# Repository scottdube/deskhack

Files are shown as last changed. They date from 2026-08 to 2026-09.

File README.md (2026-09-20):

# deskhack

Home Assistant control and height readback for an **ErgoSwiss hydraulic standing
desk** running a **LOGICDATA COMPACT-e-3-VAL-ES-US** control box ("Compact-3-eco",
software V290) — without buying the vendor Memory handset, and without opening
either sealed box.

The desk shipped with a dumb up/down panel: no presets, no display. This project
taps the 7-pin DIN handset cable inline, drives the button lines from an ESP32
through optocouplers, and reads the desk's height from a previously undocumented
serial broadcast the control box sends on one of the handset pins. The original
panel keeps working in parallel.

As far as I can tell this is the first public decode of the COMPACT-e-**3**
handset bus. The well-known reverse-engineering projects
([RoboDesk](https://github.com/phord/RoboDesk),
[logicdata-standing-desk](https://github.com/DanielHabenicht/logicdata-standing-desk))
target the COMPACT-e-2L, whose framing differs in an important way (see below).

## The protocol

Everything below was measured on real hardware with a $12 FX2LP logic analyzer
and `sigrok-cli`; nothing is copied from other models' documentation.

### Physical

7-pin DIN (DIN 45329 family) between handset and control box. Wire colours in
the cheap extension cable used for the tap:

| wire | function |
|---|---|
| brown  | GND |
| red | +5V supply to handset |
| white  | HS line — assert **high** to drive **UP** |
| yellow | HS line — assert **high** to drive **DOWN** |
| green  | HS line, unused by the basic panel (memory functions) |
| blue | HS line, unused by the basic panel (memory functions) |
| black  | serial data **out of** the box, idles high |

Button lines are **active-high** and high-impedance: the box's inputs are
sensitive enough that a multimeter in ohms mode will command motion (ask me how
I know). A dumb panel is nothing but switches connecting HS lines to the +5V
rail.

### Serial framing

The data line is **1000 baud, 9 data bits, no parity, 1 stop, LSB-first** — a
classic 9-bit multi-drop bus. Community docs for the COMPACT-e-2L describe
"1000 baud with even parity"; on this box that is a misread of the 9th data
bit. The framing here was solved by constraint propagation over the raw bit
runs (every 0 must sit inside a frame; see `dataline.py` and `messages.py`),
not assumed.

Packets are two 9-bit words, sent only **when the displayed height changes**
(one packet per inch of travel) plus a fixed handshake burst at the start of
any button press. Packet: `0x07F` header, then the payload word.

### Height

```
height_inches = (245 - (payload & 0xFF)) / 2
```

Verified against a tape measure at four points across the full travel
(69–96 cm on this desk, 27.0–38.0 in): every reading within 0.5 cm. The box
counts pump-motor Hall pulses internally, so this is the same position the
controller itself acts on.

### The 8N1 trick

You do not need 9-bit UART support to read this bus — a plain **8N1** UART at
1000 baud recovers every payload byte intact. But how the packet arrives
depends on how the UART handles framing errors, and real ESP32 silicon
differs from the obvious simulation:

- A UART that **discards** error bytes and resyncs bit-by-bit (what a naive
  software decoder does) sees the header mis-frame into a constant `0xFE`
  sync marker followed by the height byte.
- The **ESP32 keeps** framing-error bytes (verified on an ESP32-WROOM-32,
  ESP-IDF 5.5). Packets arrive as `00 7F <payload>`: the header comes through
  verbatim as `0x7F`, each framing error also emits a `0x00` artifact, and
  the payload byte is unmangled.

Either way the sync-then-payload structure survives. On the ESP32: skip
`0x00`, treat `0x7F` as "next byte is payload".

Filtering the handshake burst is easy thanks to an accident of the encoding:
**real heights are always odd bytes** (`245 - 2*inches`), and the handshake
constants are even or outside the travel range — except `0x0BF`, which
aliases a true 27.0 in reading. Its tell is timing: as a handshake word it
arrives within ~400 ms of the others, as a real height it arrives alone, so
reject `0xBF` seen within 600 ms of other handshake traffic. The working
lambda is in `desk.yaml`.

## Hardware

Eight components, all through-hole:

- 2 × PC817 optocoupler (or CPC1017N photoMOS) — GPIO drives the LED through
  330 Ω; the output side connects a button line to the +5V rail, exactly as a
  finger on the panel does
- 2 × 100 kΩ bleed, opto emitter → GND, so leakage can't float the
  high-impedance inputs
- 3 × 22 kΩ — divider (22k : 44k) dropping the 5 V data line to 3.3 V for the
  ESP32's RX
- ESP32 dev board on its own USB supply, grounds tied at the DIN cable

The tap itself is a male-female 7-pin DIN extension cable cut in half and
landed on lever nuts, so the whole thing unplugs back to stock in seconds.

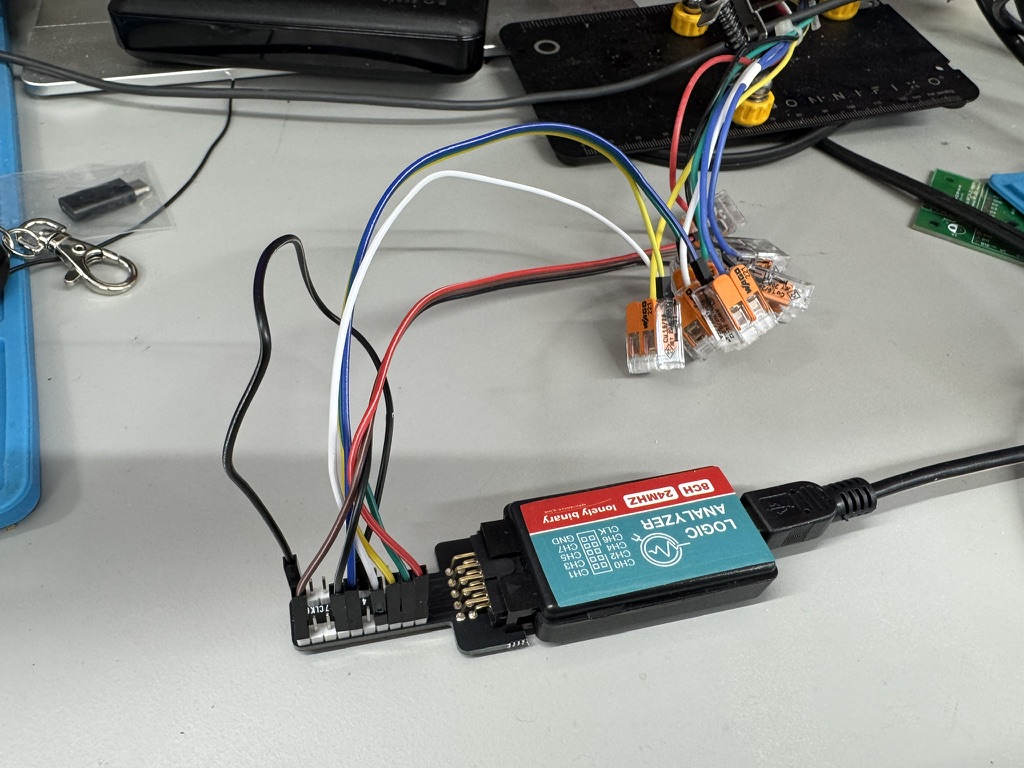
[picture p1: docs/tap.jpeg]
The tap: a 7-pin DIN extension cut in half, each conductor landed in a WAGO 221 lever nut with a pigtail out to the logic analyzer


Nothing is soldered and nothing on the desk is modified — the box and the
original panel each keep their own connector, and the lever nuts sit in
between. Pull the two halves and the desk is stock again.

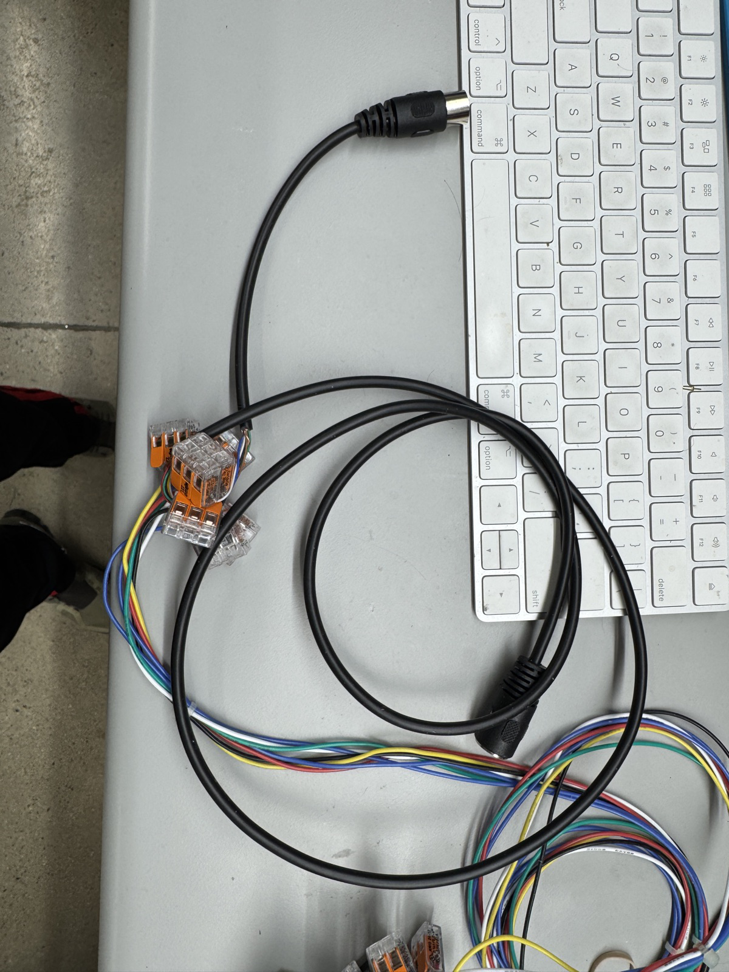
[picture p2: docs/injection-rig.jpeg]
The injection rig: a cheap male-female 7-pin DIN extension cut in half, both halves landed in WAGO 221 lever nuts. Male end to the control box, female end to the original handset.


**This rig is the whole trick, and it generalises.** It is a $10 extension
cable, not the desk's harness. Cutting it gives you seven conductors broken out
into lever nuts, which is simultaneously a **probe point** for the logic
analyzer and an **injection point** for the ESP32 — read the bus and drive it
without ever putting a knife near the cable that came with the machine. Get it
wrong, unplug two connectors, and the desk has never been touched. Any bus
that runs through a detachable cable can be attacked this way.

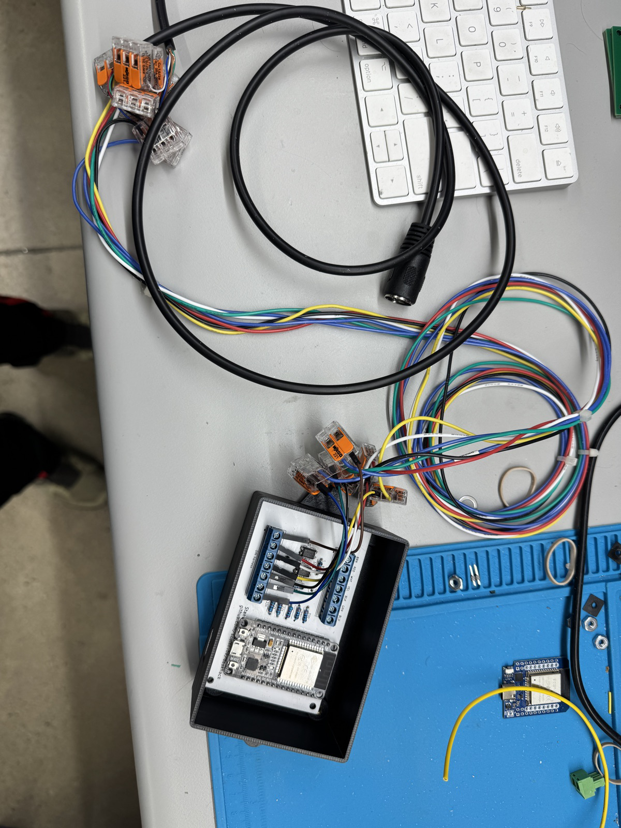
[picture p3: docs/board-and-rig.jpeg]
The finished board wired to the rig on the bench, before install. The wire-colour legend along each terminal block matches the DIN conductor colours.


The board keeps the same idea: J1 and J4 are wired straight through, so the
control box and the original handset each land on their own terminal block and
the ESP32 sits across the pair. The panel goes on working exactly as before.

### The cable shield is left floating — on purpose

The handset cable is seven conductors **plus a shield**, and the shield is not
grounded here. That is deliberate, and it is worth stating plainly because the
instinct on seeing an ungrounded shield is that somebody forgot.

**It is not grounded in the desk's own wiring.** The two halves of the tap have
their drains joined to each other, so the shield stays electrically continuous
end to end exactly as it was before the cable was cut — and it terminates
nowhere, exactly as it did before.

Why not "improve" it: **the whole design goal is that the control box cannot
tell the difference.** Everything else here is built that way — the original
panel keeps working, the box keeps its own connector, nothing is soldered to
the desk. Bonding the shield to logic ground would be a change to a mains-fed
system whose internal grounding we cannot see, in exchange for a benefit
nothing has demonstrated a need for. If the box grounds the shield at its end,
adding a second bond creates a loop.

No idea *why* LOGICDATA left it floating. Matching what the manufacturer did is
the conservative choice when you do not know the reason.

`kicad/` contains a KiCad 10 project (ERC-clean, footprints assigned) with the
interface circuit and a 30-pin ESP32 DevKit V1 socket, ready for board layout.
The schematic is *generated* — edit `kicad/gen_sch.py` and rerun rather than
editing the sheet, or retire the generator once you start hand-routing.

## Firmware

`desk.yaml` is a complete ESPHome configuration:

- height sensor via the 8N1 trick (hardware UART, zero protocol code)
- target-height number entity + sit/stand/stop buttons for Home Assistant
- bang-bang seek loop (feedback is 1-inch granular; there is nothing finer to
  chase)
- **duty-cycle watchdog** — the box is rated 2 min on / 18 min off and this is
  enforced in firmware, don't remove it; Drive Budget and Budget Recovery
  sensors expose how much motion is left before lockout. The budget persists
  across reboots (and credits real elapsed time while powered off), so an OTA
  can't hand you a fresh one. A diagnostic **Reset Duty Budget** button exists
  for bench work — deliberate operator action only, never automate it
- stall detection (no height change while driving → stop)
- a template **cover** face (0% = bottom of travel, 100% = top) so voice
  assistants can drive it with built-in position intents — no custom
  sentences required, and it provides a voice "stop"

### Voice control: use the cover, not the buttons

The cover face is not a convenience — on Home Assistant it is the *only* part of
this firmware a voice assistant can reach without extra configuration, and that
is worth stating plainly because the sit/stand buttons look like the obvious
target.

HA's local sentence matcher only recognises entities in a fixed set of domains.
Measured against `home-assistant-intents` (en, 851 sentence templates): every
template with a `{name}` slot carries a `requires_context.domain` allow-list, and
the union of every domain any template can target is

    binary_sensor climate cover fan input_boolean lawn_mower light lock
    media_player person scene script sensor switch todo vacuum valve weather

**`button` is not in that set.** So `button.<device>_sit` / `_stand` cannot be
matched by any phrasing — and **entity aliases do not help**, because an alias
only supplies candidate text for a `{name}` slot and there is no `{name}`
template that accepts a button.

What this costs depends on your pipeline. With a purely local assistant, the
buttons are simply unreachable by voice. With an LLM conversation agent and
"prefer handling commands locally" enabled, they still work — but they miss the
local matcher every time and fall through to the LLM, so every "sit"/"stand"
pays a full cloud round trip while `cover` commands answer instantly. That
asymmetry is easy to misread as a problem with the desk, the ESP32 or the WiFi;
it is none of those.

Two ways to get fast sit/stand:

- **Use the cover.** "raise / lower the standing desk" works with no extra
  config. Note the cover's ends are the ends of *travel*, so "lower" goes to the
  bottom of travel, which may be below your preferred sitting height.
- **Add custom sentences** mapping your own phrases to an `intent_script` that
  presses the buttons. This keeps one definition of "sit" and "stand" — in this
  firmware, next to the duty-cycle watchdog — and preserves a non-travel-end
  sitting height.

Copy `wifi.yaml.example` to `wifi.yaml` first.

## Analysis tools

Everything runs on a capture exported to CSV
(`sigrok-cli -i cap.sr -O csv > cap.csv`):

| tool | what it does |
|---|---|
| `probe.py` | per-channel characterization: idle level, edges, implied baud from narrowest pulse |
| `timeline.py` | button lines as a deglitched state timeline |
| `dataline.py` | bit-time histogram and exhaustive UART framing search |
| `messages.py` | packet segmentation + solved 9N1 decode — the useful one |
| `viewer.py` | renders a capture as a self-contained interactive HTML waveform viewer |
| `make_test_capture.py` | synthetic capture for self-testing the toolchain |

## Safety notes

- The control box is mains-fed and sealed. Nothing here requires opening it,
  and you shouldn't.
- Disconnect mains before plugging/unplugging anything on the handset cable —
  the box enters a re-commissioning state (down-only until re-homed) if the
  handset connection glitches while powered.
- Respect the 2/18 duty cycle. A "nudge every N minutes" automation will
  overheat the box; preset seeks lasting seconds are fine.
- If the box loses its reference: drive to the bottom, hold both panel buttons
  5 s, drive to the top, hold both 5 s (the §4.2 commissioning procedure — it
  works with a plain up/down panel).

## Applies to

Verified on: ErgoSwiss "Steuerung Compact-3-eco 110V V290" (P/N 124.30290),
LOGICDATA type `COMPACT-e-3-VAL-ES-US`, revision 3/1.9.14, US 120 V. The VAL
firmware is hydraulic-specific ("only for hydraulic lift system — modified
parameters"). Other COMPACT-e-3 variants likely match; measure before you
trust — `probe.py` will tell you in one capture.

## License

MIT. If this saved you a €63 handset or an afternoon with a logic analyzer,
pay it forward.

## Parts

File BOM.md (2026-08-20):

# Bill of materials — Standing Desk Controller

ESPHome controller for the LOGICDATA standing desk (deskhack) - PC817 opto interface, ESP32

**InvenTree part** `#795`  ·  **Build** `BO-0003` (Complete)

| Qty | Part | ID | Where it lives |
|---:|---|---|---|
| 1 | ESP-WROOM-32 ESP32 ESP-32S Dev Board 2.4GHz WiFi+BT | `62` | B3-R6C3 |
| 1 | 7-Pin DIN Male-Female Extension Cable 5ft | `786` | no stock |
| 3 | Resistor 22k 1% 1/4W | `621` | Kit - EAONE Resistor 30-value |
| 2 | Resistor 100k 1% 1/4W | `625` | Kit - EAONE Resistor 30-value |
| 2 | Resistor 330R 1% 1/4W | `611` | Kit - EAONE Resistor 30-value |
| 2 | (8Sets) Terminal Block Set, 3 4 5 6 7 8 10 12 Positions 600V 15A Dual Row Screw Terminals Strip + Pr | `283` | no stock |
| 2 | PC817 Optocoupler DIP-4 | `17` | B3-R3C1 |

## Notes on individual lines

- **7-Pin DIN Male-Female Extension Cable 5ft** — Desk-to-controller handset cable

---

_Generated from InvenTree on 2026-08-19 — do not edit by hand._
_Regenerate:_ `itq run link_repos.py && write_boms.py`

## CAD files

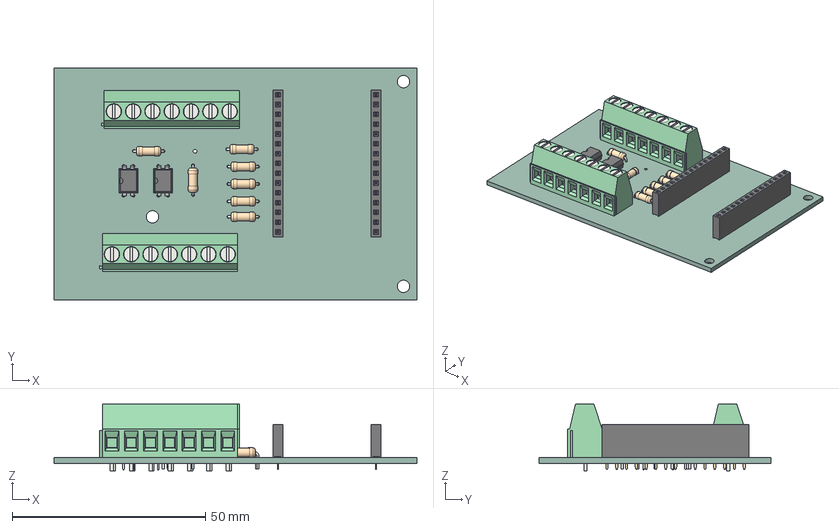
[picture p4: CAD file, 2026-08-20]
mech/desk-board.step
94.0 x 60.0 x 17.3 mm
PinSocket_1x15_P2.54mm_Vertical x 2
DIP-4_W7.62mm x 2
R_Axial_DIN0207_L63mm_D25mm_P762mm_Horizontal x 7
TerminalBlock_Phoenix_MKDS-1,5-7_1x07_P5.00mm_Horizontal x 2
desk_PCB

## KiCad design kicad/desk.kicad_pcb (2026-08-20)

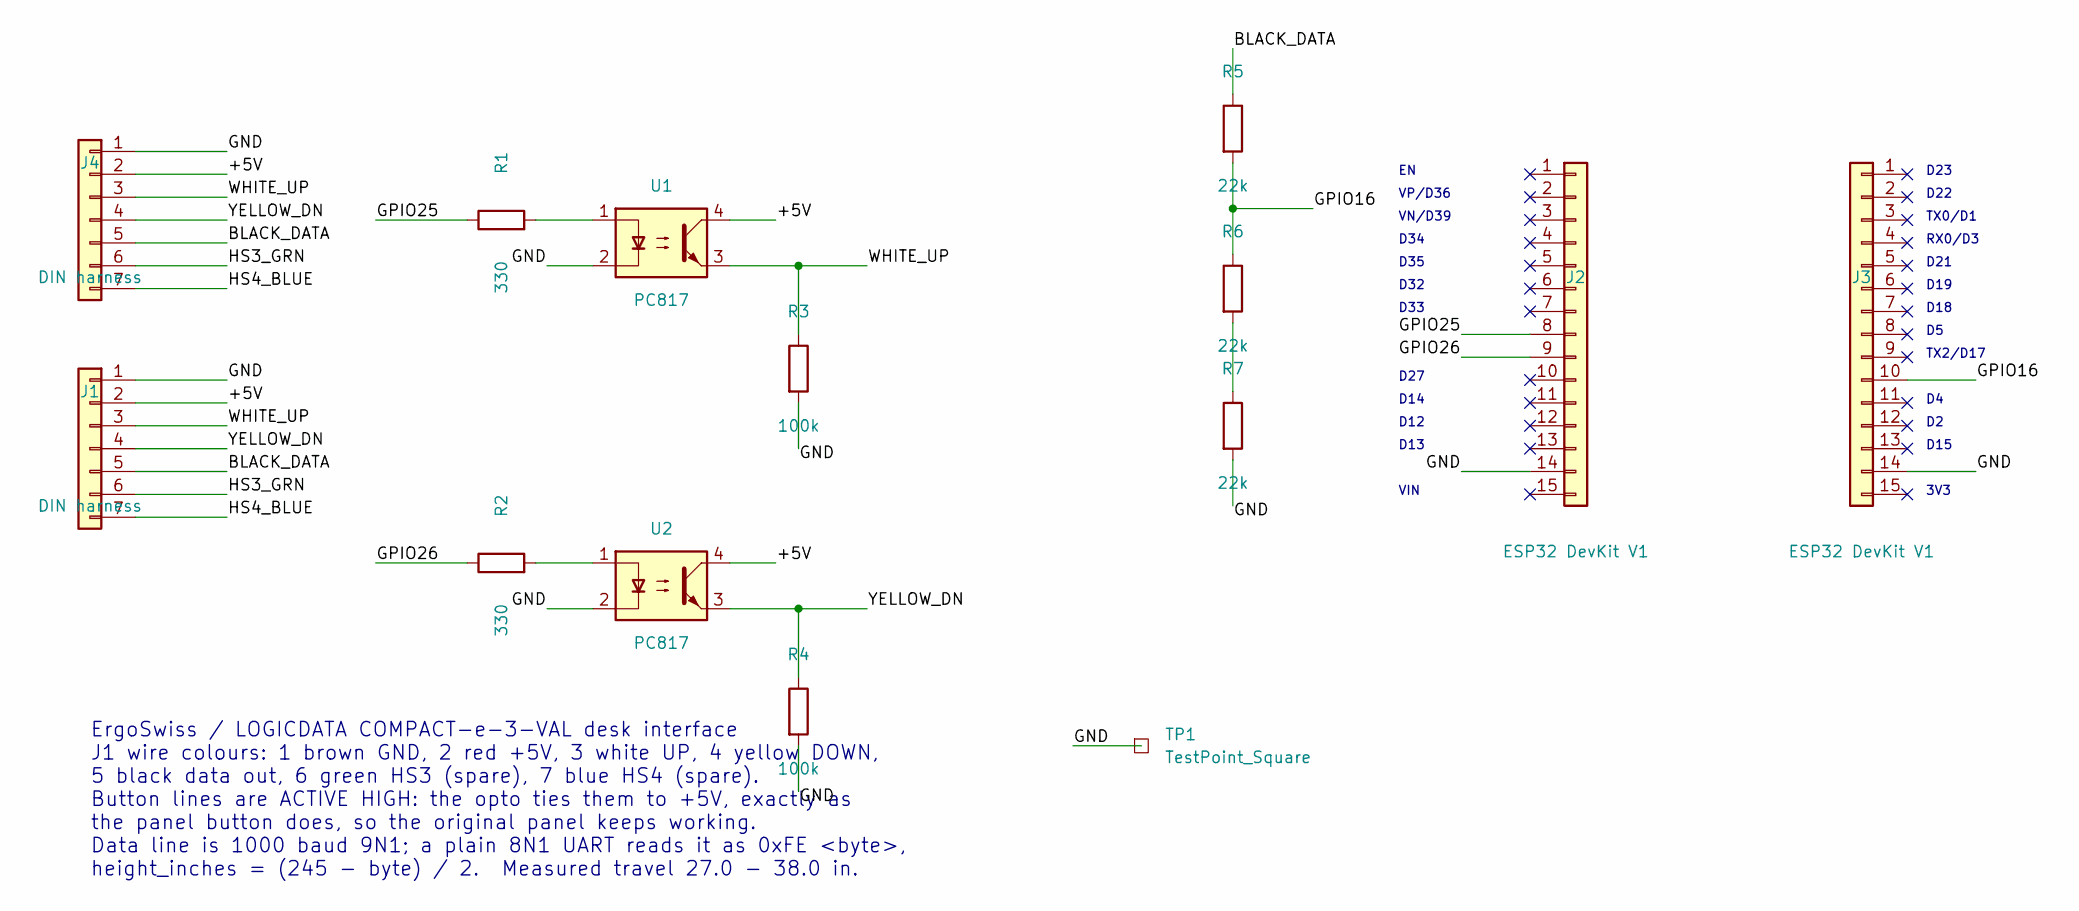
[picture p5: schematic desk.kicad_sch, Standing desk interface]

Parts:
J1, J4: DIN harness; TerminalBlock_Phoenix_MKDS-1,5-7_1x07_P5.00mm_Horizontal
J2, J3: ESP32 DevKit V1; PinSocket_1x15_P2.54mm_Vertical
R1, R2: 330; R_Axial_DIN0207_L6.3mm_D2.5mm_P7.62mm_Horizontal
R3, R4: 100k; R_Axial_DIN0207_L6.3mm_D2.5mm_P7.62mm_Horizontal
R5, R6, R7: 22k; R_Axial_DIN0207_L6.3mm_D2.5mm_P7.62mm_Horizontal
TP1: TestPoint_Square; TestPoint_Pad_2.0x2.0mm
U1, U2: PC817; DIP-4_W7.62mm

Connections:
/+5V: J1.2, J4.2, U1.4, U2.4
/BLACK_DATA: J1.5, J4.5, R5.1
/GND: J1.1, J2.14, J3.14, J4.1, R3.2, R4.2, R7.2, TP1.1 (1_1), U1.2, U2.2
/GPIO16: J3.10, R5.2, R6.1
/GPIO25: J2.8, R1.1
/GPIO26: J2.9, R2.1
/HS3_GRN: J1.6, J4.6
/HS4_BLUE: J1.7, J4.7
/WHITE_UP: J1.3, J4.3, R3.1, U1.3
/YELLOW_DN: J1.4, J4.4, R4.1, U2.3
unnamed: R1.2, U1.1
unnamed: R2.2, U2.1
unnamed: R6.2, R7.1

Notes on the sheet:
D12
D35
ErgoSwiss / LOGICDATA COMPACT-e-3-VAL desk interface J1 wire colours: 1 brown GND, 2 red +5V, 3 white UP, 4 yellow DOWN, 5 black data out, 6 green HS3 (spare), 7 blue HS4 (spare). Button lines are ACTIVE HIGH: the opto ties them to +5V, exactly as the panel button does, so the original panel keeps 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
RX0/D3
D33
D19
D18
TX2/D17
D22
3V3
D23
TX0/D1
D32
D14
D15
D21
D34
D13
VP/D36
VN/D39
VIN
D27

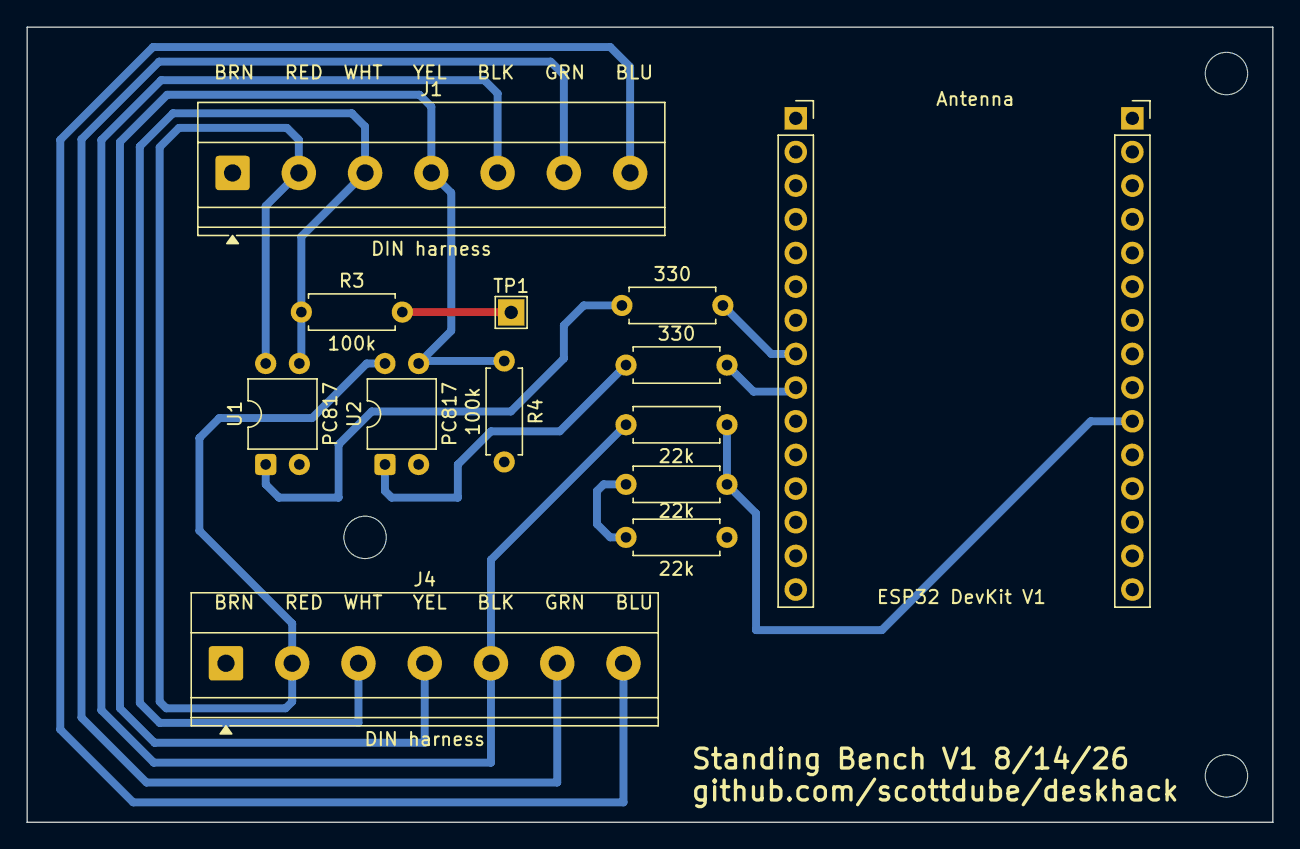
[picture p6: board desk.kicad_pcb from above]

Board: 2 copper layers, 94.0 x 60.0 mm, 14 parts (0 on the bottom side), 13 nets.

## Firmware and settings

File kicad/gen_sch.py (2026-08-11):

#!/usr/bin/env python3
"""Generate the desk interface schematic as a KiCad 10 project.

Usage:
    python3 gen_sch.py [outdir]

Symbol definitions are lifted from the installed KiCad libraries and embedded
in the .kicad_sch, so the file opens standalone without library lookups.
"""
import os
import sys
import uuid as uuidlib

import sexp

LIB = "/Applications/KiCad/KiCad.app/Contents/SharedSupport/symbols"
NS = uuidlib.UUID("6f2b1d3e-0000-4000-8000-000000000000")
SHEET = "b1c0ffee-0000-4000-8000-000000000001"

_n = [0]


def uid():
    """Deterministic UUIDs so regenerating gives a clean diff."""
    _n[0] += 1
    return str(uuidlib.uuid5(NS, str(_n[0])))


# ---------------------------------------------------------------- symbols

_cache = {}


def libsym(lib, name):
    if (lib, name) not in _cache:
        tree = sexp.parse(open(f"{LIB}/{lib}.kicad_sym").read())
        for s in sexp.find(tree, "symbol"):
            if s[1] == f'"{name}"':
                _cache[(lib, name)] = s
                break
        else:
            raise KeyError(f"{lib}:{name}")
    return _cache[(lib, name)]


def pins_of(lib, name):
    """{number: (x, y)} in symbol space, from every unit/body-style block."""
    out = {}
    for sub in sexp.find(libsym(lib, name), "symbol"):
        for p in sexp.find(sub, "pin"):
            at = sexp.first(p, "at")
            num = sexp.first(p, "number")[1].strip('"')
            out[num] = (float(at[1]), float(at[2]))
    return out


def place_pin(px, py, x, y, rot, mirror):
    """Symbol-space pin -> sheet coordinates.

    Schematic Y runs downward while symbol Y runs up, hence the negation.
    """
    if mirror == "y":
        px = -px
    if rot == 0:
        dx, dy = px, -py
    elif rot == 90:
        dx, dy = py, px
    elif rot == 180:
        dx, dy = -px, py
    elif rot == 270:
        dx, dy = -py, -px
    else:
        raise ValueError(rot)
    return (round(x + dx, 4), round(y + dy, 4))


# ---------------------------------------------------------------- emitters

items = []
used = {}


def comp(lib, name, ref, value, x, y, rot=0, mirror=None, footprint="",
         val_off=6.35):
    used[(lib, name)] = True
    pins = pins_of(lib, name)
    body = [f'\t(symbol\n\t\t(lib_id "{lib}:{name}")\n\t\t(at {x} {y} {rot})']
    if mirror:
        body.append(f"\t\t(mirror {mirror})")
    body.append(
        f"\t\t(unit 1)\n\t\t(exclude_from_sim no)\n\t\t(in_bom yes)\n"
        f"\t\t(on_board yes)\n\t\t(dnp no)\n\t\t(uuid \"{uid()}\")"
    )
    for pname, pval, off, hide in (
        ("Reference", ref, -6.35, False),
        ("Value", value, val_off, False),
        ("Footprint", footprint, 0, True),
        ("Datasheet", "~", 0, True),
    ):
        h = "\n\t\t\t\t(hide yes)" if hide else ""
        body.append(
            f'\t\t(property "{pname}" "{pval}"\n'
            f"\t\t\t(at {x} {round(y + off, 4)} 0)\n"
            f"\t\t\t(effects\n\t\t\t\t(font\n\t\t\t\t\t(size 1.27 1.27)\n"
            f"\t\t\t\t){h}\n\t\t\t)\n\t\t)"
        )
    for num in sorted(pins, key=lambda s: (len(s), s)):
        body.append(f'\t\t(pin "{num}"\n\t\t\t(uuid "{uid()}")\n\t\t)')
    body.append(
        f'\t\t(instances\n\t\t\t(project "desk"\n\t\t\t\t(path "/{SHEET}"\n'
        f'\t\t\t\t\t(reference "{ref}")\n\t\t\t\t\t(unit 1)\n'
        f"\t\t\t\t)\n\t\t\t)\n\t\t)"
    )
    body.append("\t)")
    items.append("\n".join(body))
    return {n: place_pin(*p, x, y, rot, mirror) for n, p in pins.items()}


def wire(a, b):
    items.append(
        f"\t(wire\n\t\t(pts\n\t\t\t(xy {a[0]} {a[1]}) (xy {b[0]} {b[1]})\n"
        f"\t\t)\n\t\t(stroke\n\t\t\t(width 0)\n\t\t\t(type default)\n\t\t)\n"
        f'\t\t(uuid "{uid()}")\n\t)'
    )


def label(text, at, rot=0, justify="left bottom"):
    items.append(
        f'\t(label "{text}"\n\t\t(at {at[0]} {at[1]} {rot})\n\t\t(effects\n'
        f"\t\t\t(font\n\t\t\t\t(size 1.27 1.27)\n\t\t\t)\n"
        f"\t\t\t(justify {justify})\n\t\t)\n"
        f'\t\t(uuid "{uid()}")\n\t)'
    )


def junction(at):
    items.append(
        f"\t(junction\n\t\t(at {at[0]} {at[1]})\n\t\t(diameter 0)\n"
        f"\t\t(color 0 0 0 0)\n"
        f'\t\t(uuid "{uid()}")\n\t)'
    )


def noconn(at):
    items.append(f'\t(no_connect\n\t\t(at {at[0]} {at[1]})\n\t\t(uuid "{uid()}")\n\t)')


def note(text, at, size=1.27):
    esc = text.replace("\n", "\\n")
    items.append(
        f'\t(text "{esc}"\n\t\t(exclude_from_sim no)\n'
        f"\t\t(at {at[0]} {at[1]} 0)\n\t\t(effects\n\t\t\t(font\n"
        f"\t\t\t\t(size {size} {size})\n\t\t\t)\n\t\t\t(justify left top)\n"
        f'\t\t)\n\t\t(uuid "{uid()}")\n\t)'
    )


# ---------------------------------------------------------------- circuit

def build():
    # ---- DIN harness in, on the left, mirrored so its pins face the circuit
    j1 = comp("Connector_Generic", "Conn_01x07", "J1", "DIN harness",
              63.5, 101.6, mirror="y",
              footprint="TerminalBlock_Phoenix:TerminalBlock_Phoenix_MKDS-1,5-7_1x07_P5.00mm_Horizontal")
    names = {
        "1": ("GND", "brown"),
        "2": ("+5V", "red"),
        "3": ("WHITE_UP", "white"),
        "4": ("YELLOW_DN", "yellow"),
        "5": ("BLACK_DATA", "black"),
    }
    for num, (net, colour) in names.items():
        p = j1[num]
        end = (p[0] + 10.16, p[1])
        wire(p, end)
        label(net, end)
    for num in ("6", "7"):                      # green / blue, HS3 / HS4
        p = j1[num]
        end = (p[0] + 5.08, p[1])
        wire(p, end)
        noconn(end)

    # ---- opto channels. PC817: 1 anode, 2 cathode, 3 emitter, 4 collector.
    for ref_u, ref_r, ref_b, gpio, net, y in (
        ("U1", "R1", "R3", "GPIO25", "WHITE_UP", 76.2),
        ("U2", "R2", "R4", "GPIO26", "YELLOW_DN", 114.3),
    ):
        r = comp("Device", "R", ref_r, "330", 109.22, y, rot=90,
                 footprint="Resistor_THT:R_Axial_DIN0207_L6.3mm_D2.5mm_P10.16mm_Horizontal")
        u = comp("Isolator", "PC817", ref_u, "PC817", 127.0, y + 2.54,
                 footprint="Package_DIP:DIP-4_W7.62mm")
        label(gpio, (r["2"][0] - 10.16, y))
        wire((r["2"][0] - 10.16, y), r["2"])
        wire(r["1"], u["1"])                      # series R into the LED

        wire(u["2"], (u["2"][0] - 5.08, u["2"][1]))   # cathode to ground
        label("GND", (u["2"][0] - 5.08, u["2"][1]), justify="right bottom")

        wire(u["4"], (u["4"][0] + 5.08, u["4"][1]))   # collector to +5V
        label("+5V", (u["4"][0] + 5.08, u["4"][1]))

        # Emitter drives the desk's button line, with a bleed to ground so
        # phototransistor leakage cannot float a high-impedance input high.
        tap = (u["3"][0] + 15.24, u["3"][1])
        wire(u["3"], tap)
        label(net, tap)
        bleed = comp("Device", "R", ref_b, "100k", u["3"][0] + 7.62,
                     u["3"][1] + 11.43,
                     footprint="Resistor_THT:R_Axial_DIN0207_L6.3mm_D2.5mm_P10.16mm_Horizontal")
        junction((bleed["1"][0], u["3"][1]))
        wire((bleed["1"][0], u["3"][1]), bleed["1"])
        wire(bleed["2"], (bleed["2"][0], bleed["2"][1] + 5.08))
        label("GND", (bleed["2"][0], bleed["2"][1] + 5.08), justify="left top")

    # ---- 3:1 divider dropping the 5V data line to 3.33V for the ESP32
    x = 190.5
    label("BLACK_DATA", (x, 57.15), justify="left bottom")
    r5 = comp("Device", "R", "R5", "22k", x, 66.04,
              footprint="Resistor_THT:R_Axial_DIN0207_L6.3mm_D2.5mm_P10.16mm_Horizontal")
    r6 = comp("Device", "R", "R6", "22k", x, 83.82,
              footprint="Resistor_THT:R_Axial_DIN0207_L6.3mm_D2.5mm_P10.16mm_Horizontal")
    r7 = comp("Device", "R", "R7", "22k", x, 99.06,
              footprint="Resistor_THT:R_Axial_DIN0207_L6.3mm_D2.5mm_P10.16mm_Horizontal")
    wire((x, 57.15), r5["1"])
    tap = (x, 74.93)
    wire(r5["2"], r6["1"])
    junction(tap)
    wire(tap, (x + 15.24, 74.93))
    label("GPIO16", (x + 15.24, 74.93))
    wire(r6["2"], r7["1"])
    wire(r7["2"], (x, 107.95))
    label("GND", (x, 107.95), justify="left top")

    # ---- ESP32 DevKit V1 (30-pin) as the two socket rows a carrier board
    # actually holds. Silk names run EN..VIN down the left row and
    # D23..3V3 down the right row with the USB jack at the bottom.
    LEFT = ["EN", "VP/D36", "VN/D39", "D34", "D35", "D32", "D33",
            "D25", "D26", "D27", "D14", "D12", "D13", "GND", "VIN"]
    RIGHT = ["D23", "D22", "TX0/D1", "RX0/D3", "D21", "D19", "D18", "D5",
             "TX2/D17", "RX2/D16", "D4", "D2", "D15", "GND", "3V3"]
    NETS = {"D25": "GPIO25", "D26": "GPIO26", "RX2/D16": "GPIO16",
            "GND": "GND"}
    for ref, x, names, mirror in (("J2", 228.6, LEFT, None),
                                  ("J3", 260.35, RIGHT, "y")):
        j = comp("Connector_Generic", "Conn_01x15", ref,
                 "ESP32 DevKit V1", x, 88.9, mirror=mirror, val_off=24.13,
                 footprint="Connector_PinSocket_2.54mm:"
                           "PinSocket_1x15_P2.54mm_Vertical")
        sign = 1 if mirror else -1          # stub direction away from body
        for i, silk in enumerate(names, 1):
            p = j[str(i)]
            if silk in NETS:
                end = (round(p[0] + sign * 7.62, 4), p[1])
                wire(p, end)
                label(NETS[silk], end,
                      justify="left bottom" if sign > 0 else "right bottom")
            else:
                # Unused socket position: flag it, annotate the silk name as
                # plain text so it does not become a one-pin net.
                noconn(p)
                tx = round(p[0] + sign * 2.0, 4)
                note(silk, (tx if sign > 0 else tx - 12.7, p[1] - 0.8),
                     size=1.0)

    note("ErgoSwiss / LOGICDATA COMPACT-e-3-VAL desk interface\\n"
         "J1 wire colours: 1 brown GND, 2 red +5V, 3 white UP, 4 yellow DOWN,\\n"
         "5 black data out, 6 green HS3 (spare), 7 blue HS4 (spare).\\n"
         "Button lines are ACTIVE HIGH: the opto ties them to +5V, exactly as\\n"
         "the panel button does, so the original panel keeps working.\\n"
         "Data line is 1000 baud 9N1; a plain 8N1 UART reads it as 0xFE <byte>,\\n"
         "height_inches = (245 - byte) / 2.  Measured travel 27.0 - 38.0 in.",
         (63.5, 132.08), size=1.6)


# ---------------------------------------------------------------- output

def write(outdir):
    build()
    libs = []
    for (lib, name) in used:
        blk = sexp.dump(libsym(lib, name), indent=2)
        libs.append(blk.replace(f'(symbol "{name}"', f'(symbol "{lib}:{name}"', 1))

    doc = [
        "(kicad_sch",
        "\t(version 20260306)",
        '\t(generator "eeschema")',
        '\t(generator_version "10.0")',
        f'\t(uuid "{SHEET}")',
        '\t(paper "A4")',
        "\t(title_block",
        '\t\t(title "Standing desk interface")',
        '\t\t(company "deskhack")',
        '\t\t(comment 1 "ESP32 <-> ErgoSwiss compact-3-eco handset bus")',
        "\t)",
        "\t(lib_symbols",
        "\n".join(libs),
        "\t)",
        "\n".join(items),
        "\t(sheet_instances",
        '\t\t(path "/"',
        '\t\t\t(page "1")',
        "\t\t)",
        "\t)",
        "\t(embedded_fonts no)",
        ")",
    ]
    os.makedirs(outdir, exist_ok=True)
    with open(f"{outdir}/desk.kicad_sch", "w") as f:
        f.write("\n".join(doc) + "\n")
    with open(f"{outdir}/desk.kicad_pro", "w") as f:
        f.write('{\n  "board": {},\n  "boards": [],\n  "libraries": '
                '{"pinned_footprint_libs": [], "pinned_symbol_libs": []},\n'
                '  "meta": {"filename": "desk.kicad_pro", "version": 3},\n'
                '  "net_settings": {"classes": [{"name": "Default", '
                '"clearance": 0.2, "track_width": 0.25}]},\n'
                '  "sheets": [["' + SHEET + '", "Root"]],\n'
                '  "text_variables": {}\n}\n')
    print(f"wrote {outdir}/desk.kicad_sch")


if __name__ == "__main__":
    write(sys.argv[1] if len(sys.argv) > 1 else ".")

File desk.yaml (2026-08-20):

substitutions:
  device_name: desk
  friendly_name: Standing Desk

# ErgoSwiss hydraulic standing desk on a LOGICDATA COMPACT-e-3-VAL-ES-US
# control box ("Compact-3-eco", software V290). Full reverse-engineering
# writeup: https://github.com/scottdube/deskhack
#
# ============================ ARCHITECTURE (settled 2026-08-11) ==============
# Tap on the 7-pin DIN handset cable, inline between box and the original
# up/down panel (panel keeps working in parallel). Wire colours are the cut
# extension cable's, verified by measurement — NOT the DIN pin numbers.
#
#   brown  GND     red +5V     white UP     yellow DOWN     black data-out
#   green/blue = HS3/HS4, unused by the dumb panel (memory-handset lines)
#
# BUTTON LINES ARE ACTIVE-HIGH and high-impedance: a press connects the line
# to +5V (an ohmmeter's source current was enough to command motion). Drive:
#   GPIO -> 330R -> PC817 LED; opto output ties line to +5V like a finger.
#   100k bleed emitter->GND so leakage can't float an input high.
#   Optos release dark => unpowered/booting ESP32 cannot move the desk.
#
# HEIGHT: the box broadcasts on black at 1000 baud 9N1 (9-bit multi-drop),
# one packet per INCH of displayed change plus a handshake burst on any
# button press. A plain 8N1 UART recovers the payload; on real ESP32
# silicon (which KEEPS framing-error bytes) each packet arrives as
# 00 7F <payload>: skip 0x00, sync on 0x7F, then inches = (245 - b) / 2.
# Real heights are always ODD bytes; handshake words are even, gated, or
# (0xBF only) rejected by a 600ms timing guard. Details in the RX lambda.
# Verified against tape at 4 points across full travel, all within 0.5 cm.
# Overnight drift test 2026-08-12: none (77 cm -> 77 cm under load).
#
# CHANNELS (30-pin DevKit V1):
#   D25 GPIO25 -> opto U1 -> white  (UP)
#   D26 GPIO26 -> opto U2 -> yellow (DOWN)
#   RX2 GPIO16 <- 22k / (22k+22k) divider <- black (5V bus, 3.3V pin)
#
# DUTY CYCLE: the box is rated 2 min on / 18 min off and the watchdog below
# enforces it. Do not remove it, do not build nudge-every-N-minutes
# automations on top of this device.

esphome:
  name: ${device_name}
  friendly_name: ${friendly_name}
  on_boot:
    priority: -100
    then:
      - script.execute: all_stop

esp32:
  board: esp32dev
  framework:
    type: esp-idf

logger:

api:

ota:
  - platform: esphome

# Copy wifi.yaml.example -> wifi.yaml and fill it in. wifi.yaml is gitignored.
wifi: !include wifi.yaml

time:
  - platform: homeassistant
    id: ha_time
    on_time_sync:
      then:
        # First valid clock after boot: credit the cooldown that elapsed while
        # we were off. Guarded by a one-shot so periodic re-syncs don't
        # double-decay against the 500ms loop that also drains run_s.
        - if:
            condition:
              lambda: return !id(budget_credited);
            then:
              - lambda: |-
                  id(budget_credited) = true;
                  auto now = id(ha_time).now();
                  if (!now.is_valid() || id(budget_stamp) == 0) return;
                  uint32_t t = now.timestamp;
                  if (t <= id(budget_stamp)) return;
                  float off_s = (float) (t - id(budget_stamp));
                  id(run_s) = fmaxf(0.0f, id(run_s) - 0.1f * off_s);
                  if (id(run_s) <= 0.0f) id(locked_out) = false;
                  ESP_LOGI("desk", "credited %.0fs offline, budget now %.0f%%",
                           off_s, 100.0f - id(run_s));

uart:
  id: deskbus
  rx_pin: GPIO16
  baud_rate: 1000
  data_bits: 8
  parity: NONE
  stop_bits: 1
  # Commissioning aid: dump raw RX bytes to the log. Height packets appear
  # as 00 7F <byte> groups. Remove once the bus is proven.
  debug:
    direction: RX
    after:
      timeout: 100ms
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

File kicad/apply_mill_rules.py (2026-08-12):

#!/usr/bin/env python3
"""Copy the proven isolation-milling design rules into a KiCad project.

Usage:
    python3 apply_mill_rules.py <target.kicad_pro> [...]

Rules and net classes are lifted from sln-geo-aux-heat, which has actually
been milled and whose G-code lives in pcbmill's proven_out fixtures -- so
these numbers are field-tested rather than guessed. Everything else in the
target project file is left untouched.
"""
import json
import os
import sys

SRC = ("/Users/scottdube/code/sln-ha-config/electronics/kicad/"
       "sln-geo-aux-heat/sln-geo-aux-heat.kicad_pro")

# Nets matched to the Power class automatically, so a board does not need
# hand-assignment every time. Patterns are KiCad wildcard syntax.
POWER_PATTERNS = ["GND", "+5V", "+3V3", "+12V", "VCC", "VIN"]

# The committed v1-as-cut board used 0.4mm on the Default class and 0.5mm on
# Power. Later (uncommitted) revisions moved everything to 0.5mm, which is
# what actually gets milled, so both classes are normalized to it here.
CLEARANCE = 0.5


def load_reference():
    src = json.load(open(SRC))
    rules = dict(src["board"]["design_settings"]["rules"])
    classes = [dict(c) for c in src["net_settings"]["classes"]]
    rules["min_clearance"] = CLEARANCE
    for c in classes:
        c["clearance"] = CLEARANCE
    return rules, classes


def apply(path, rules, classes):
    d = json.load(open(path)) if os.path.exists(path) else {}

    ds = d.setdefault("board", {}).setdefault("design_settings", {})
    ds["rules"] = rules
    ds["track_widths"] = [0.0, 0.6, 1.0, 1.5, 2.0]   # 0.0 = use netclass
    ds["via_dimensions"] = [{"diameter": 0.0, "drill": 0.0},
                            {"diameter": 1.6, "drill": 0.8}]

    ns = d.setdefault("net_settings", {})
    ns["classes"] = classes
    ns.setdefault("meta", {"version": 5})
    ns.setdefault("net_colors", None)
    ns.setdefault("netclass_assignments", None)
    ns["netclass_patterns"] = [{"netclass": "Power", "pattern": p}
                               for p in POWER_PATTERNS]

    d.setdefault("libraries",
                 {"pinned_footprint_libs": [], "pinned_symbol_libs": []})
    d.setdefault("boards", [])
    d.setdefault("text_variables", {})
    meta = d.setdefault("meta", {})
    meta.setdefault("filename", os.path.basename(path))
    meta.setdefault("version", 3)

    json.dump(d, open(path, "w"), indent=2)
    return d


def main():
    if len(sys.argv) < 2:
        sys.exit(__doc__)
    rules, classes = load_reference()
    for path in sys.argv[1:]:
        apply(path, rules, classes)
        widths = {c["name"]: c["track_width"] for c in classes}
        print(f"{path}: min_track={rules['min_track_width']} "
              f"min_clearance={rules['min_clearance']} classes={widths}")


if __name__ == "__main__":
    main()

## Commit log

2026-08-11 Reverse-engineer LOGICDATA COMPACT-e-3-VAL handset bus; ESP32 desk control
    Protocol decode (1000 baud 9N1 multi-drop, height = (245 - byte)/2),
    sigrok analysis tools, ESPHome config with duty-cycle watchdog, and an
    ERC-clean KiCad 10 interface board project.
    [desk.kicad_sch]
2026-08-11 Add generated starter PCB: footprints placed and netted, DevKit rows at measured 25.4mm
    [desk.kicad_pcb]
2026-08-12 Fix missing schematic<->board linkage; retire the PCB generator
    Generated footprints carried no (path "/<symbol-uuid>"), so Update PCB
    from Schematic could not match them and treated every symbol as new.
    link_pcb.py injects the paths by reference designator. Board layout is
    now hand-maintained; gen_pcb.py removed.
    [desk.kicad_pcb, desk.kicad_sch]
2026-08-12 Resistors to P7.62mm footprints; board linked and ready to route
    [desk.kicad_pcb]
2026-08-12 Adopt proven isolation-milling design rules from geo-aux-heat
    0.6mm default / 1.0mm power tracks, 0.5mm clearance, 0.4mm min track.
    apply_mill_rules.py copies these into any project so new boards start
    mill-ready instead of with fab-house defaults.
    [apply_mill_rules.py]
2026-08-12 Bench-validated: correct 8N1 framing for real ESP32 silicon
    The ESP32 UART keeps framing-error bytes rather than discarding them,
    so packets arrive as 00 7F <payload>, not FE <payload> as simulated.
    Sync on 0x7F; heights are always odd bytes, which filters the handshake
    burst except 0xBF (aliases 27.0in) - rejected by a 600ms timing guard.
    Live height confirmed in Home Assistant.
    [desk.yaml]
2026-08-12 Fix stale 0xFE references in yaml comments
    [desk.yaml]
2026-08-12 Never restore height across reboots; fast re-learn via handshake burst
    The desk can move while the ESP32 is off, so a restored height creates a
    dead zone where seeks inside the stale error do nothing (observed as
    'target must be 4in away'). Every boot now re-learns via a 600ms button
    blip - the handshake burst's 4th packet carries current height ~300ms in,
    so no visible travel is needed. Seek loop bench-validated end to end.
    [desk.yaml]
2026-08-12 Fix seek acting on the previous target value
    ESPHome fires a template number's set_action BEFORE publishing the new
    state, so id(target_in).state read the OLD value inside the seek script.
    Every move chased the previous command, which surfaced as a phantom
    2-4 inch dead zone and 'it only moves if I change the target twice'.
    Publish the trigger's x first, then seek. Also adds a Go To Target
    button (HA sends nothing when a slider lands on its current value) and
    a seek log line that made the race visible.
    [desk.yaml]
2026-08-12 Add cover face for voice control, duty-cycle budget sensors, Sit=29
    Cover maps 27-38in onto 0-100% so HassSetPosition/open/close/stop work
    without custom sentences, and gives a voice stop the buttons never had.
    Drive Budget (%) and Budget Recovery (min) surface the 2/18 duty limit.
2026-08-13 Board ready to cut: J4 pass-through, GND pour, 3 mounting holes, DRC clean
    Export script matches the shop guide section 4 (4.6 gerbers, X2 and netlist
    attrs off, merged inch Excellon) and now emits F.Silkscreen for the laser.
    Footer corrected to solve-offsets: MX/MY are per-board, and this board is
    not near page origin so the geo-aux-heat constants would run it off the
    fixture entirely.
    [desk.kicad_pcb, desk.kicad_sch]
2026-08-20 Add BOM.md generated from InvenTree
    Answers "what do I need to build this" without opening InvenTree, which
    matters when the repo is the thing you have open. Part IDs are included
    because they are the stable handle — names get renamed as parts are
    identified.
    Generated, not hand-maintained; the footer names the command.
2026-08-20 Board built and running: fab pipeline, firmware fixes, build photos
    Firmware: sync the public copy with the fleet version. Duty budget now
    persists across reboots and credits elapsed off-time, and a diagnostic
    Reset Duty Budget button is added for bench work. Fixes a stall-detection
    bug where all_stop fought the seek loop at ~2 Hz, burning full duty budget
    with the desk stationary. Fixes wifi.yaml.example, which nested the wifi
    key and failed on first build.
    KiCad: silkscreen legend, per-terminal wire-colour labels, 0.2 mm solder
    mask expansion.
    export_for_mill.sh: mirrored B.Mask export with mirror and geometry guards,
    rasterised legend (KiCad's stroke-font SVG imports unusably), suppress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
    [desk-board.step, desk.kicad_pcb]
2026-08-20 Document why the cable shield is left floating
    Pre-empts the obvious objection. The shield is not grounded in the desk's own
    wiring, so the tap matches it rather than "improving" it — the design goal
    throughout is that the control box cannot tell the difference. Bonding to
    logic ground would also risk a loop if the box grounds the shield at its end.
2026-09-20 Document why voice control goes through the cover, not the sit/stand buttons
    The cover face was already here and the README already said it needs no custom
    sentences. What it did not say is that the cover is the ONLY part of this
    firmware a voice assistant can reach — which makes the buttons a trap for
    anyone wiring this up, since they are the obvious target.
    Measured against home-assistant-intents (en): all 851 sentence templates that
    carry a {name} slot also carry a requires_context.domain allow-list, and the
    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
